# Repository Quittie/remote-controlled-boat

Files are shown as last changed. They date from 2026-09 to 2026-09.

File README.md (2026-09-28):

# A Remotely Operated Boat Equipped with a Set of Sensors

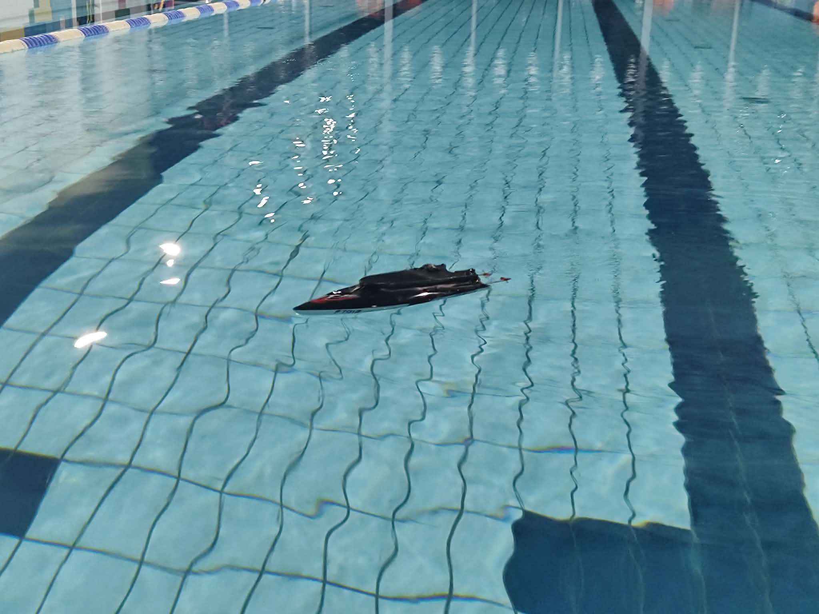
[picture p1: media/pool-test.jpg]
Boat during the pool test


Bachelor’s engineering thesis, Poznań University of Technology, 2026.

**Authors:** Piotr Trusiewicz and Michał Pietrzak  
**Supervisor:** dr inż. Bartłomiej Wicher

This project involved adapting and testing a small remote-controlled boat as an experimental platform. It was designed to compare two steering methods: a servo-operated rudder and differential thrust produced by changing the speeds of the two propulsion motors.

The boat used a commercially manufactured Feilun FT012-01 hull (approximately 40 × 12 × 7 cm). The hull was purchased; it was not designed by us. Our work included the propulsion system, mechanical modifications, electronics, control software and water tests.

## My contribution

My thesis chapters covered the design assumptions, hull selection, motor and propeller tests, mechanical mounting and alignment of the propulsion components, mechanical design of the boat, and its 3D-printed parts. I designed these parts in Autodesk Inventor Professional and prepared them for printing in PLA.

The shared thesis chapter on the project results was written by both authors. Michał Pietrzak was responsible for the electrical schematic, radio-controller signal handling, steering logic, IMU integration and Wi-Fi communication. The project description below includes both the mechanical work and enough of the complete system to explain how the boat was tested.

## System overview

The boat has two RS555 DC propulsion motors, rated for 12 V and a nominal speed of 4,800 rpm. Each motor drives a shaft through a flexible coupling with a rubber insert. The shafts pass through the rear of the hull and carry propellers rotating in opposite directions.

The boat supports two steering configurations:

1. **Rudder steering:** both propulsion motors provide forward or reverse thrust, while a servo moves the rudder.
2. **Differential-thrust steering:** the rudder is removed and the relative speeds of the two motors are adjusted to turn the boat.

The control and measurement system, implemented by Michał, uses an STM32L476RG microcontroller, an ESP-01S (ESP8266) Wi-Fi module, an MPU6050 IMU and a radio receiver. The STM32 reads the controller’s PWM signals and IMU data; the ESP8266 passes data between the controller and a Python logger over Wi-Fi using WebSockets. This makes it possible to collect motion data during water tests.

## Mechanical design and printed parts

The mechanical design had to fit the purchased hull, keep the components aligned, distribute mass sensibly and protect the electronics from water. The two motors were mounted near the sides of the hull. A replacement rear section was made to route the drive shafts, and the shaft exits and hull joints were sealed with silicone.

Four parts from my design are included below, with each CAD view followed immediately by a photo of its printed or installed version:

- **Motor mount** – holds the DC motors and aligns them with the drive shafts.
- **Steering fin** – attaches to the servo and changes the direction of travel.
- **Servo cover** – fits the opening in the hull and provides a mounting opening for the servo.
- **Rear hull cap** – replaces the processed rear section and provides openings for the drive shafts.

The parts were designed for PLA printing without support structures. The cover was split into four printed sections because of the printer’s build-volume limit; the sections were joined with cyanoacrylate adhesive and sealed. The rear cap was bonded to the hull and sealed along its contact surface. The photos are build records showing that the parts were printed and used; the CAD and STL files are the main design files.

### Motor mount

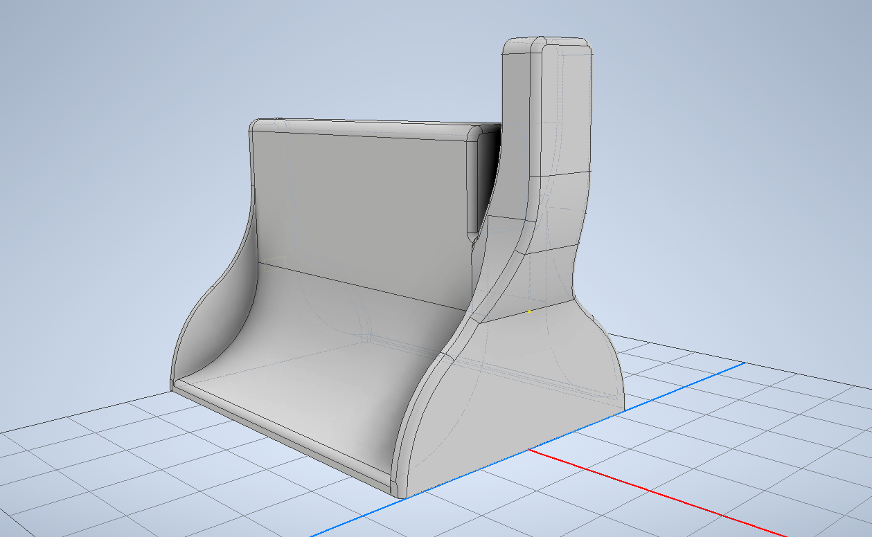
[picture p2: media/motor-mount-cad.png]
CAD model of the motor mount


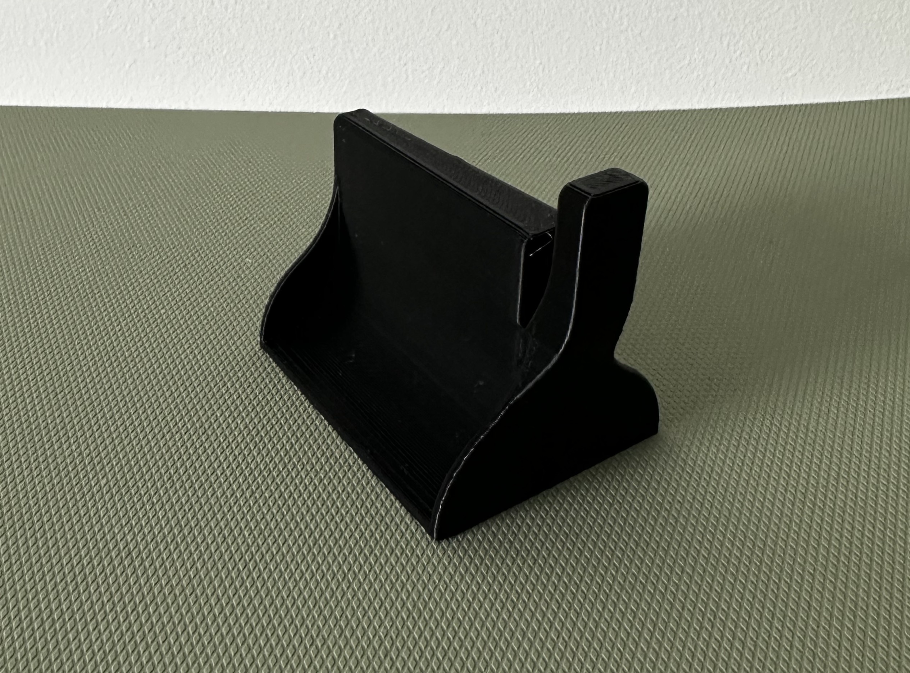
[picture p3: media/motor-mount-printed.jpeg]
Printed motor mount used in the boat


### Steering fin

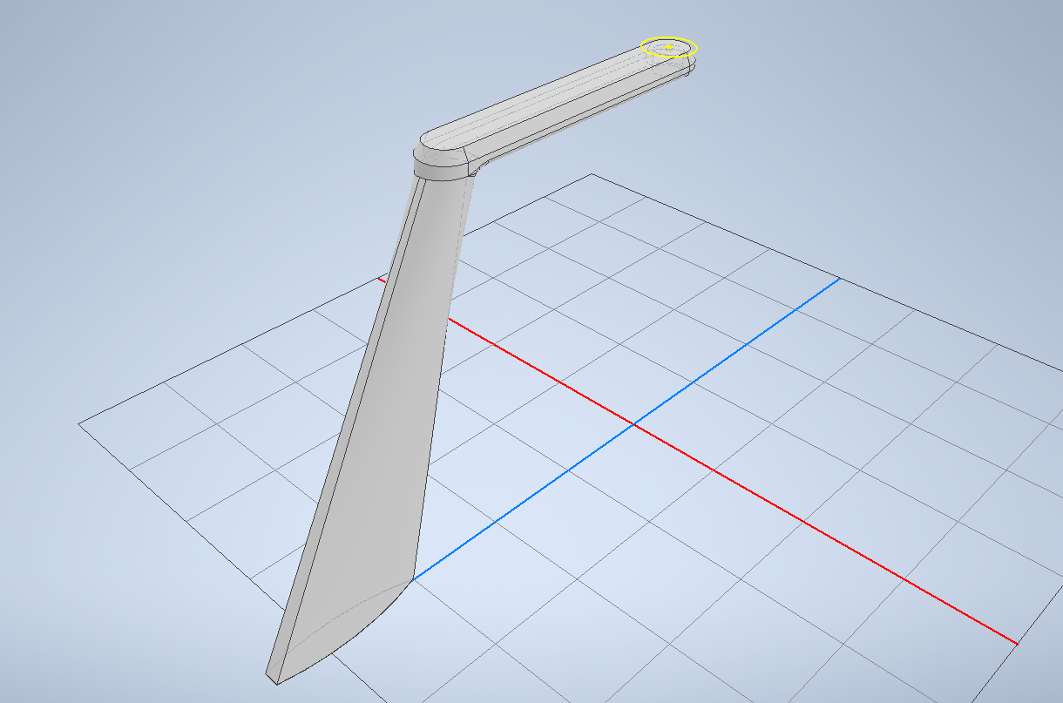
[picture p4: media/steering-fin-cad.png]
CAD model of the steering fin


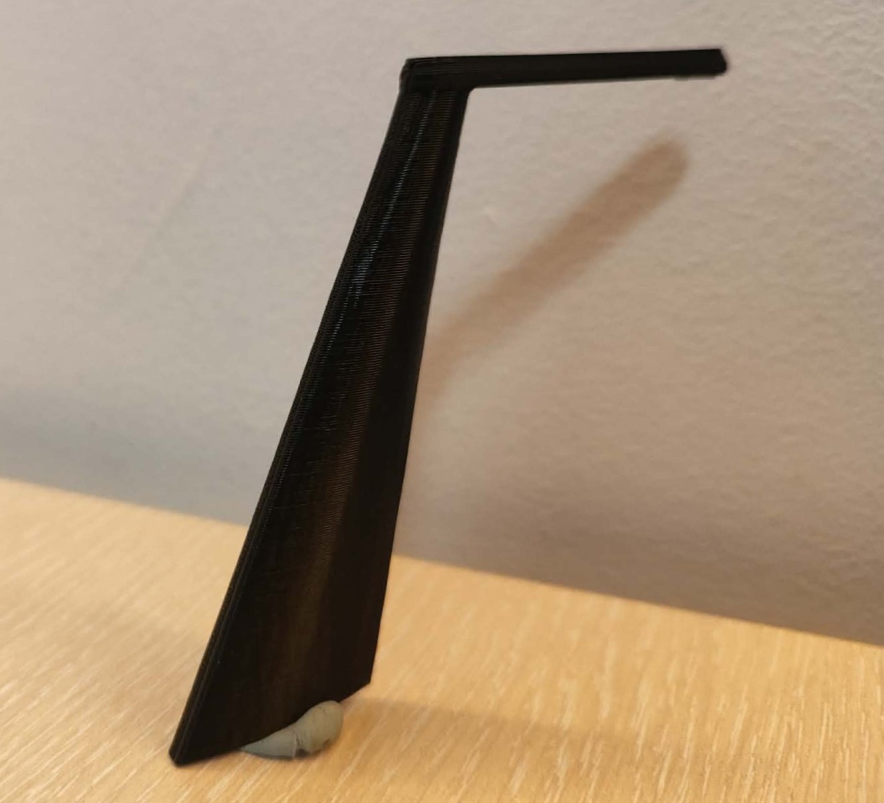
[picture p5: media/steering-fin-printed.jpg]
Printed steering fin


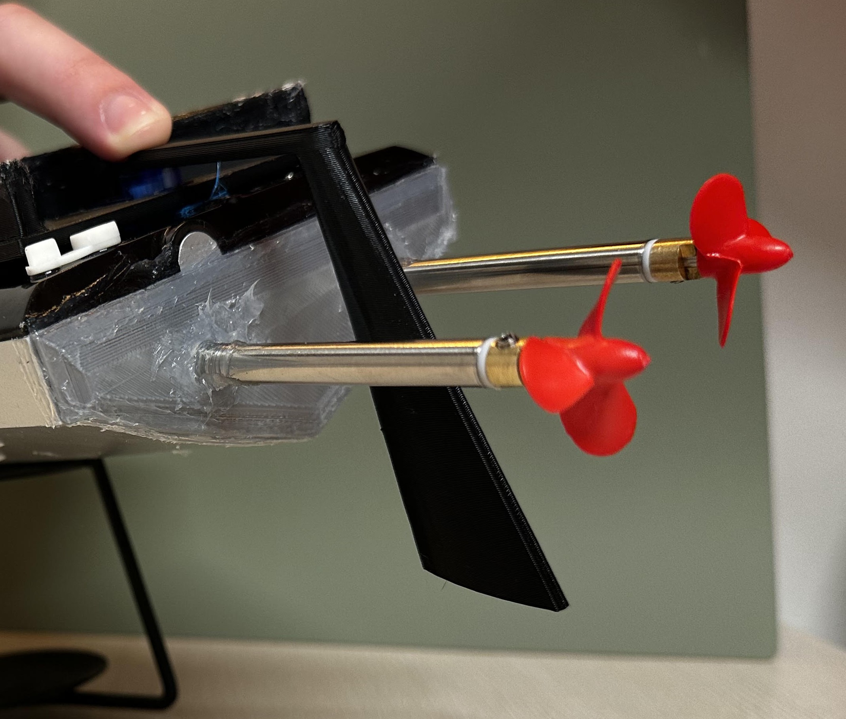
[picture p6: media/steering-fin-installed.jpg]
Steering fin installed on the boat


### Servo cover

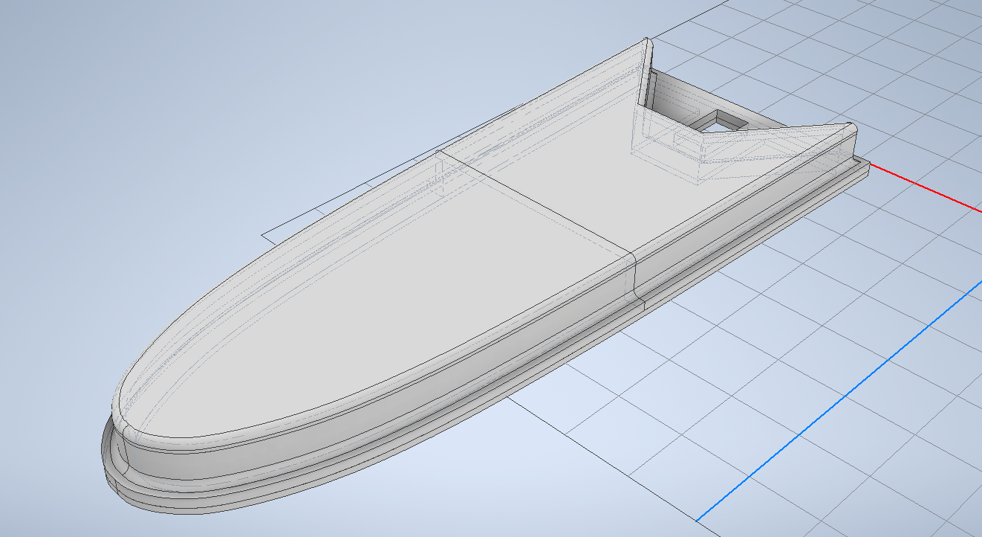
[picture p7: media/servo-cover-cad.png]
CAD model of the servo cover


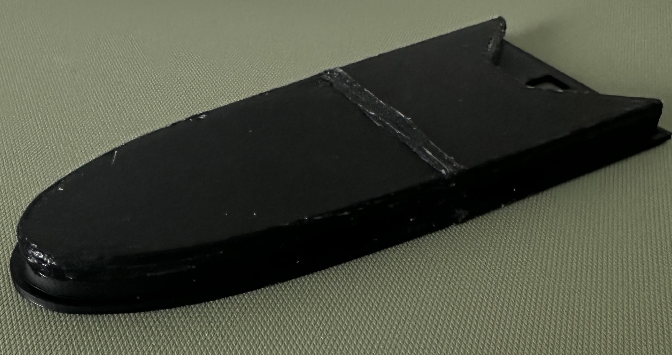
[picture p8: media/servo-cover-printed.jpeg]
Printed servo cover


### Rear hull cap

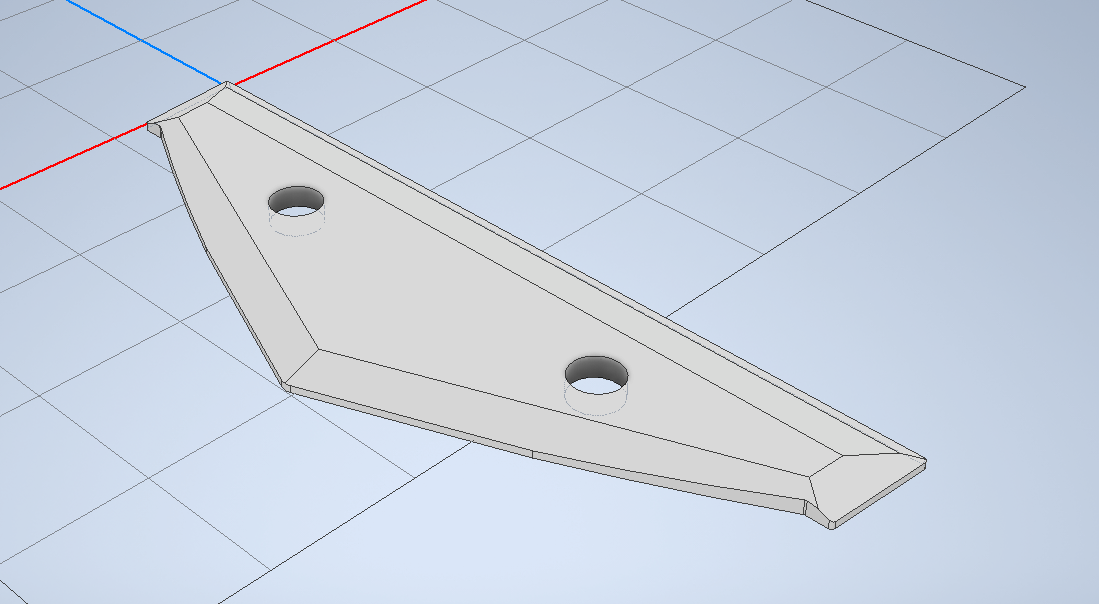
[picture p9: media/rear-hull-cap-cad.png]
CAD model of the replacement rear hull section


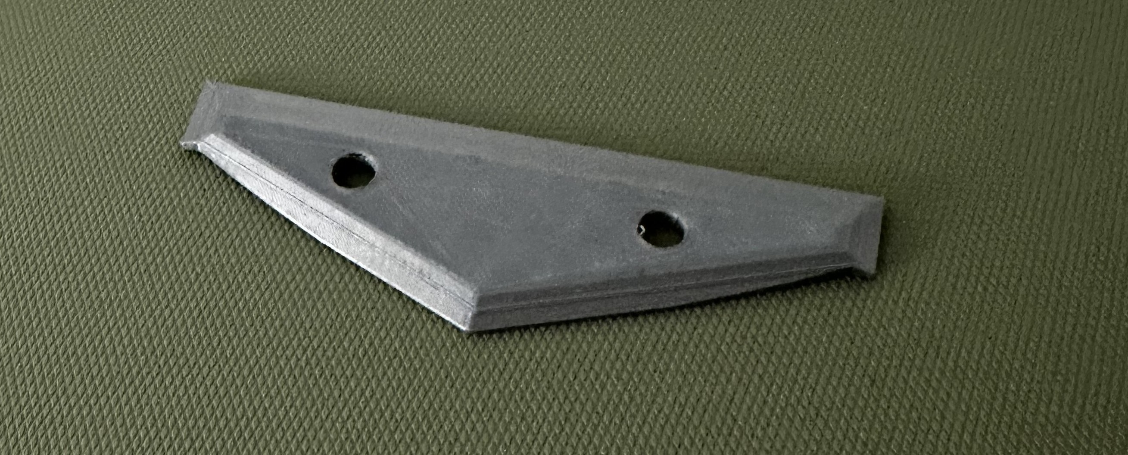
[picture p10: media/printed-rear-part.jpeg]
Printed replacement rear hull part


## Motor and propeller tests

Before installing the propulsion system, two- and three-blade propellers were compared on a test stand. A motor and propeller were suspended from a dynamometer. For different supply voltages, thrust was calculated from the change in the measured force; rotational speed and electrical quantities were also recorded. Solid plastic propellers were used instead of printed ones because they were considered stronger at high rotational speeds.

The two-blade propeller produced higher thrust, but also required more electrical power. The three-blade propeller produced less thrust but loaded the motor more evenly. Based on this trade-off, the three-blade propeller was selected for the initial boat configuration. The plots show results from this test setup and should not be treated as a universal comparison of propellers.

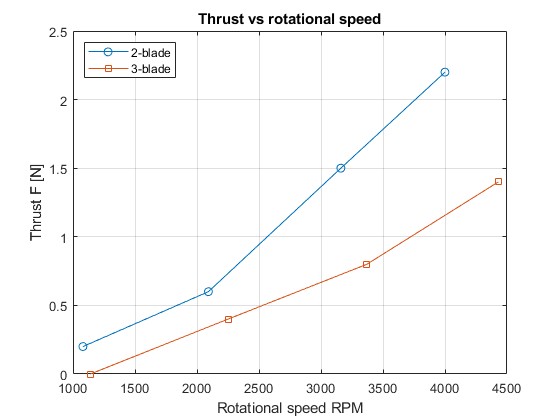
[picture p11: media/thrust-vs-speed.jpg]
Measured thrust versus rotational speed


## Water-test results

The boat was tested in a swimming pool. It floated level and returned to a stable position after being tilted by hand, supporting the initial buoyancy and mass-distribution assumptions. The installed internal components had a reported total mass of 0.875 kg. The thesis compared this with an estimated reference onboard mass of 2.6 kg, based on manufacturer figures for the complete boat and bare hull.

During an approximately 25-minute test, the boat remained afloat and there were no visible signs of water ingress while it was operating. A small amount of water was found under the drive shafts after the hull was opened, so the sealing was sufficient for short-term controlled testing but was not proven fully watertight.

The boat tended to turn left during forward motion and moved in a slight zigzag when forward and reverse commands were alternated. Differential-thrust steering did not provide stable steering in this mechanical configuration. The rudder also had no noticeable effect, possibly because of the unstable forward motion or the fin’s size. The measured average speed was estimated at about 0.35 m/s from a 25 m pool length completed in approximately 70 seconds; this estimate does not account for the extra distance travelled while turning.

The IMU data could not be used for a reliable acceleration analysis. The boat’s changing direction, movement on the water and an IMU that was not rigidly aligned with the boat axes affected the readings. The software system worked, although the Wi-Fi connection between the laptop and ESP module had some issues, possibly due to the water and the small antenna.

These results show both that the boat could operate as a research platform and that its steering and sealing needed further development. Suggested next steps in the thesis include checking motor thrust symmetry and mass balance, improving the steering arrangement and antenna, and making the hull easier to open for maintenance.

## Model files

| Part | Autodesk Inventor | STL |
|---|---|---|
| Motor mount | [`motor-mount.ipt`](models/motor-mount.ipt) | [`motor-mount.stl`](models/motor-mount.stl) |
| Steering fin | [`steering-fin.ipt`](models/steering-fin.ipt) | [`steering-fin.stl`](models/steering-fin.stl) |
| Servo cover | [`servo-cover.ipt`](models/servo-cover.ipt) | [`servo-cover.stl`](models/servo-cover.stl) |
| Rear hull cap | [`rear-hull-cap.ipt`](models/rear-hull-cap.ipt) | [`rear-hull-cap.stl`](models/rear-hull-cap.stl) |

The `.ipt` files are native Autodesk Inventor part files. The STL files are mesh exports for viewing and 3D-printing workflows.

## Attribution and reuse

The four CAD/STL model pairs in the `models/` directory are released under the **Creative Commons Attribution 4.0 International (CC BY 4.0)** license. They may be used, modified and redistributed for any purpose, including commercial use, provided that credit is given to the original author and changes are indicated. See [`LICENSE-MODELS.md`](LICENSE-MODELS.md) for a suggested attribution and the license link.

Suggested attribution: *Motor mount, steering fin, servo cover and rear hull cap by Piotr Trusiewicz, from “A Remotely Operated Boat Equipped with a Set of Sensors” (2026), Poznań University of Technology. Source: https://github.com/Quittie. Changes, if any: [describe changes]. Licensed under CC BY 4.0.*

The attribution above applies to the models in `models/`; it does not relicense the purchased hull, third-party components, or materials by the other thesis author.

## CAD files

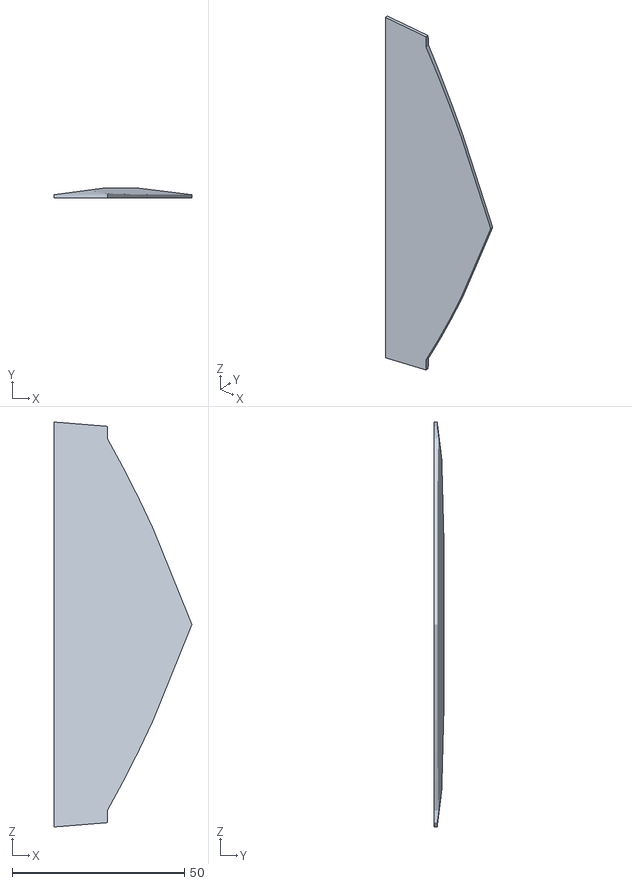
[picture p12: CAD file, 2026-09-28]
models/rear-hull-cap.stl
40.0 x 3.00 x 117.5

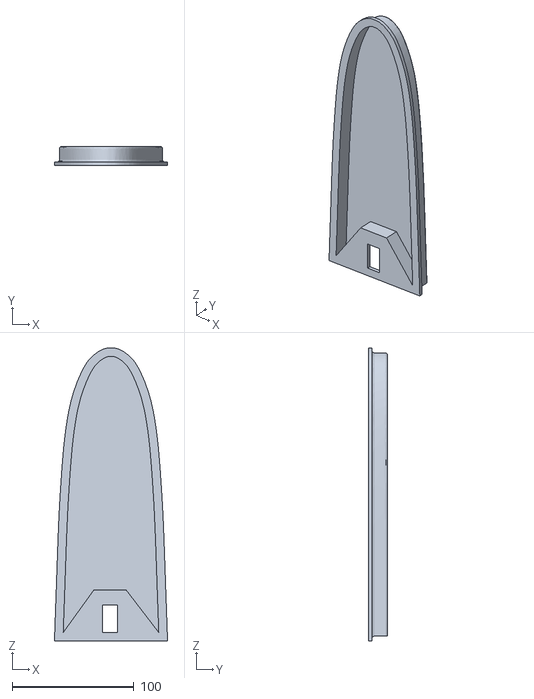
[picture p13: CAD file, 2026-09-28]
models/servo-cover.stl
93.0 x 16.0 x 241.0

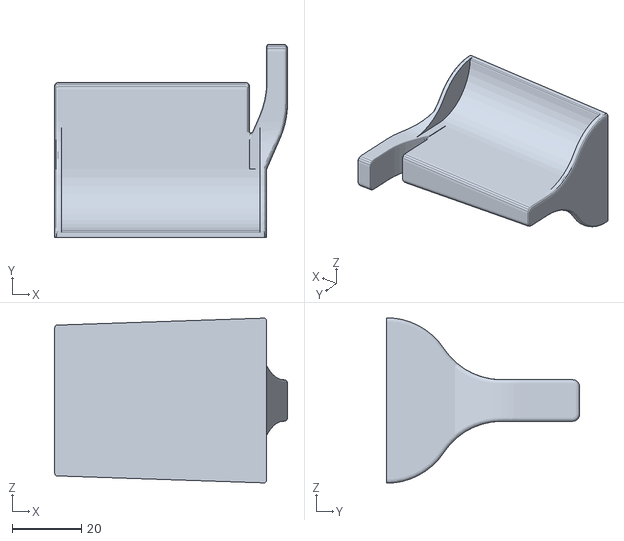
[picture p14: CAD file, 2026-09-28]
models/motor-mount.stl
67.3 x 55.8 x 47.6

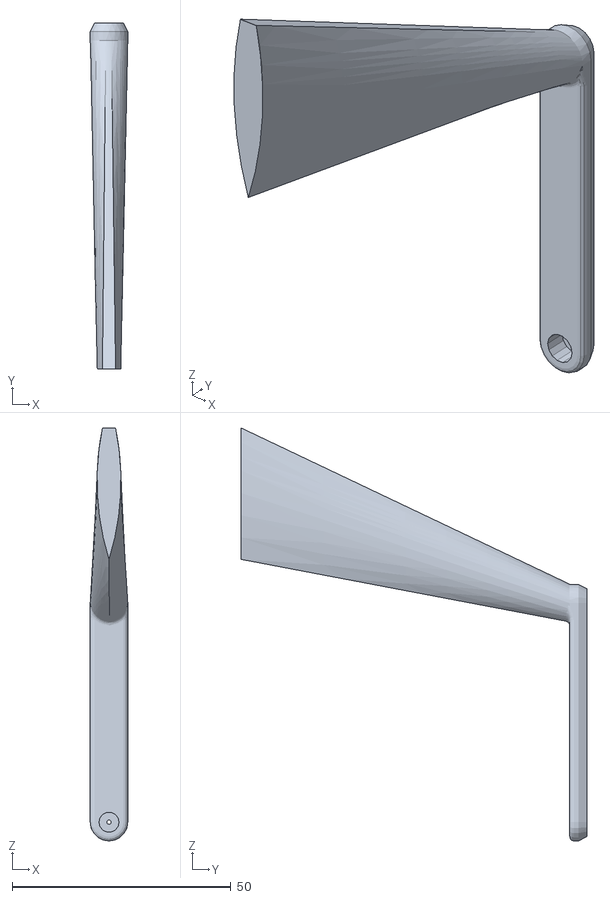
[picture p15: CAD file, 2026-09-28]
models/steering-fin.stl
8.60 x 79.1 x 94.3

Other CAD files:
models/motor-mount.ipt
models/rear-hull-cap.ipt
models/servo-cover.ipt
models/steering-fin.ipt

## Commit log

2026-09-28 Add CAD and project photos
2026-09-28 Add Autodesk Inventor and STL models
    [motor-mount.ipt, motor-mount.stl, rear-hull-cap.ipt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]
